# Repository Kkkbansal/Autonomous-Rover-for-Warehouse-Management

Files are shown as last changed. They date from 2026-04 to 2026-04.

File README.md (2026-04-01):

# Autonomous Rover for Warehouse Rack Inventory Management System

An intelligent autonomous rover designed for **real-time warehouse inventory auditing and management**, developed for **Inter IIT Tech Meet 14.0**.

The system performs **autonomous navigation, vertical rack scanning, QR-code detection, and real-time inventory reporting**, reducing manual audit cycles from **1–2 weeks to just 1 day** with **<1% discrepancy**.

---

## Project Overview

Warehouse inventory auditing is traditionally slow, labor-intensive, and error-prone.

This project introduces an **end-to-end autonomous scanning rover** capable of:

- Autonomous warehouse navigation
- Rack-level vertical scanning
- High-accuracy QR/barcode detection
- Real-time inventory status updates
- Low discrepancy stock verification

---

## Key Performance Targets

| Metric | Target |
|---|---|
| Horizontal Position Accuracy | ±10 cm |
| Vertical Position Accuracy | ±2 cm |
| Image Resolution | 1080p |
| QR Detection Reliability | >95% |
| Audit Cycle Time | 1 Day |
| Inventory Discrepancy | <1% |

---

## System Architecture

The rover consists of the following major subsystems:

- **Chassis System**
- **Differential Drive Mechanism**
- **Vertical Scissor Lift**
- **Power Management System**
- **Control System**
- **Path Planning Module**
- **QR Code Scanning Module**
- **Human Machine Interface (HMI)**

---

## Hardware Specifications

### Rover Specifications

- **Dimensions:** 600 × 355 mm
- **Weight:** ~20 kg
- **Rack Coverage:** 5 shelf levels
- **Vision Height Range:** 0.14 m – 1.75 m
- **Drive:** 2-wheel differential drive
- **Support:** Front and rear casters
- **Lift Mechanism:** 4-stage scissor lift
- **Battery:** 18V rechargeable battery
- **Backup Capacity:** 22000 mAh
- **Operational Time:** Up to 4 hours

---

## Sensors & Computing

- **Intel RealSense D455** for depth sensing and navigation
- **1080p Camera** for QR-code scanning
- **Jetson AGX Xavier** for high-level control and processing
- **ESP32** for real-time low-level motor control

---

## Mechanical Design

### Chassis

- Modular T-slot architecture
- High structural rigidity
- Controlled flexibility for uneven floors
- Optimized load distribution

### Drive System

- Differential drive configuration
- Zero-radius turning
- High traction wheel placement
- Robust caster-based stability

### Vertical System

A **4-stage pantograph scissor lift** is used for vertical scanning.

### Why Scissor Lift?

- Fully collapsible
- Compact design
- High vertical precision
- Safe for narrow aisle movement
- Easy field maintenance

---

## Control Architecture

The control system follows a **two-tier hierarchical structure**:

### High-Level Control
- Jetson AGX Xavier
- ROS2 (Cyclone DDS)
- Path planning
- Object detection
- QR scanning
- System supervision

### Low-Level Control
- ESP32
- PID-based motor control
- Encoder feedback processing
- Real-time closed-loop control

---

## Software Stack

- **ROS2**
- **Python**
- **C++**
- **OpenCV**
- **ESP32 Firmware**
- **MATLAB PID tuning**
- **Jetson SDK**

---

## Features

- Autonomous navigation
- Real-time mapping
- QR code scanning
- Inventory mismatch detection
- Rack height scanning
- Live bot telemetry
- Battery diagnostics
- Wi-Fi quality monitoring
- Remote start / pause / restart controls

---

## Human Machine Interface (HMI)

The HMI dashboard provides:

- Bot live status
- Battery health
- Wi-Fi status
- Live camera feed
- Sensor telemetry
- Start / stop scan controls
- Inventory alerts
- Success / caution notifications

---

## Future Improvements

### 1. Multi-Robot Swarm Coordination
Enable multiple autonomous rovers with centralized planning and distributed execution.

### 2. Enhanced Sensor Suite
Integrate:
- LiDAR
- Ultrasonic sensors
- Radar
- Thermal imaging

### 3. Robotic Arm Integration
Add manipulation capabilities for:
- pick and place
- object repositioning
- multi-angle scanning

---

## Applications

- Smart warehouses
- Inventory automation
- Industrial logistics
- E-commerce fulfillment centers
- Manufacturing storage systems

---

## Team

**Inter IIT Tech Meet 14.0**

Project: *Autonomous Rover for Warehouse Rack Inventory Management System*

---

## Acknowledgments

Special thanks to the Inter IIT Tech Meet organizers, mentors, and team members for their support in the development of this project.

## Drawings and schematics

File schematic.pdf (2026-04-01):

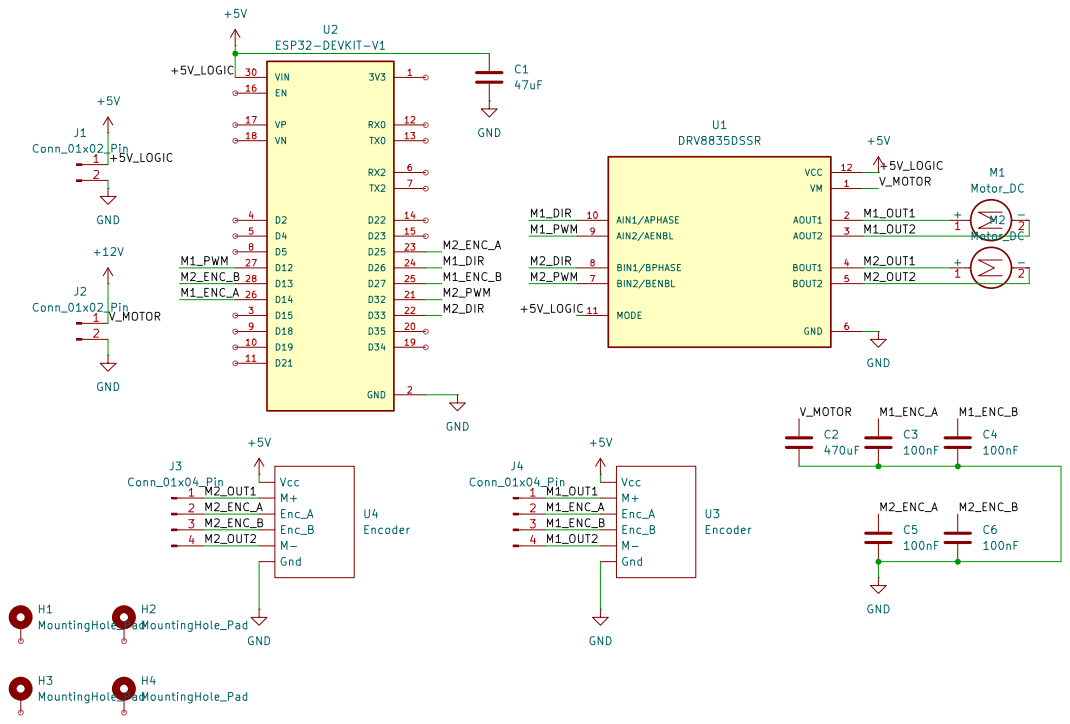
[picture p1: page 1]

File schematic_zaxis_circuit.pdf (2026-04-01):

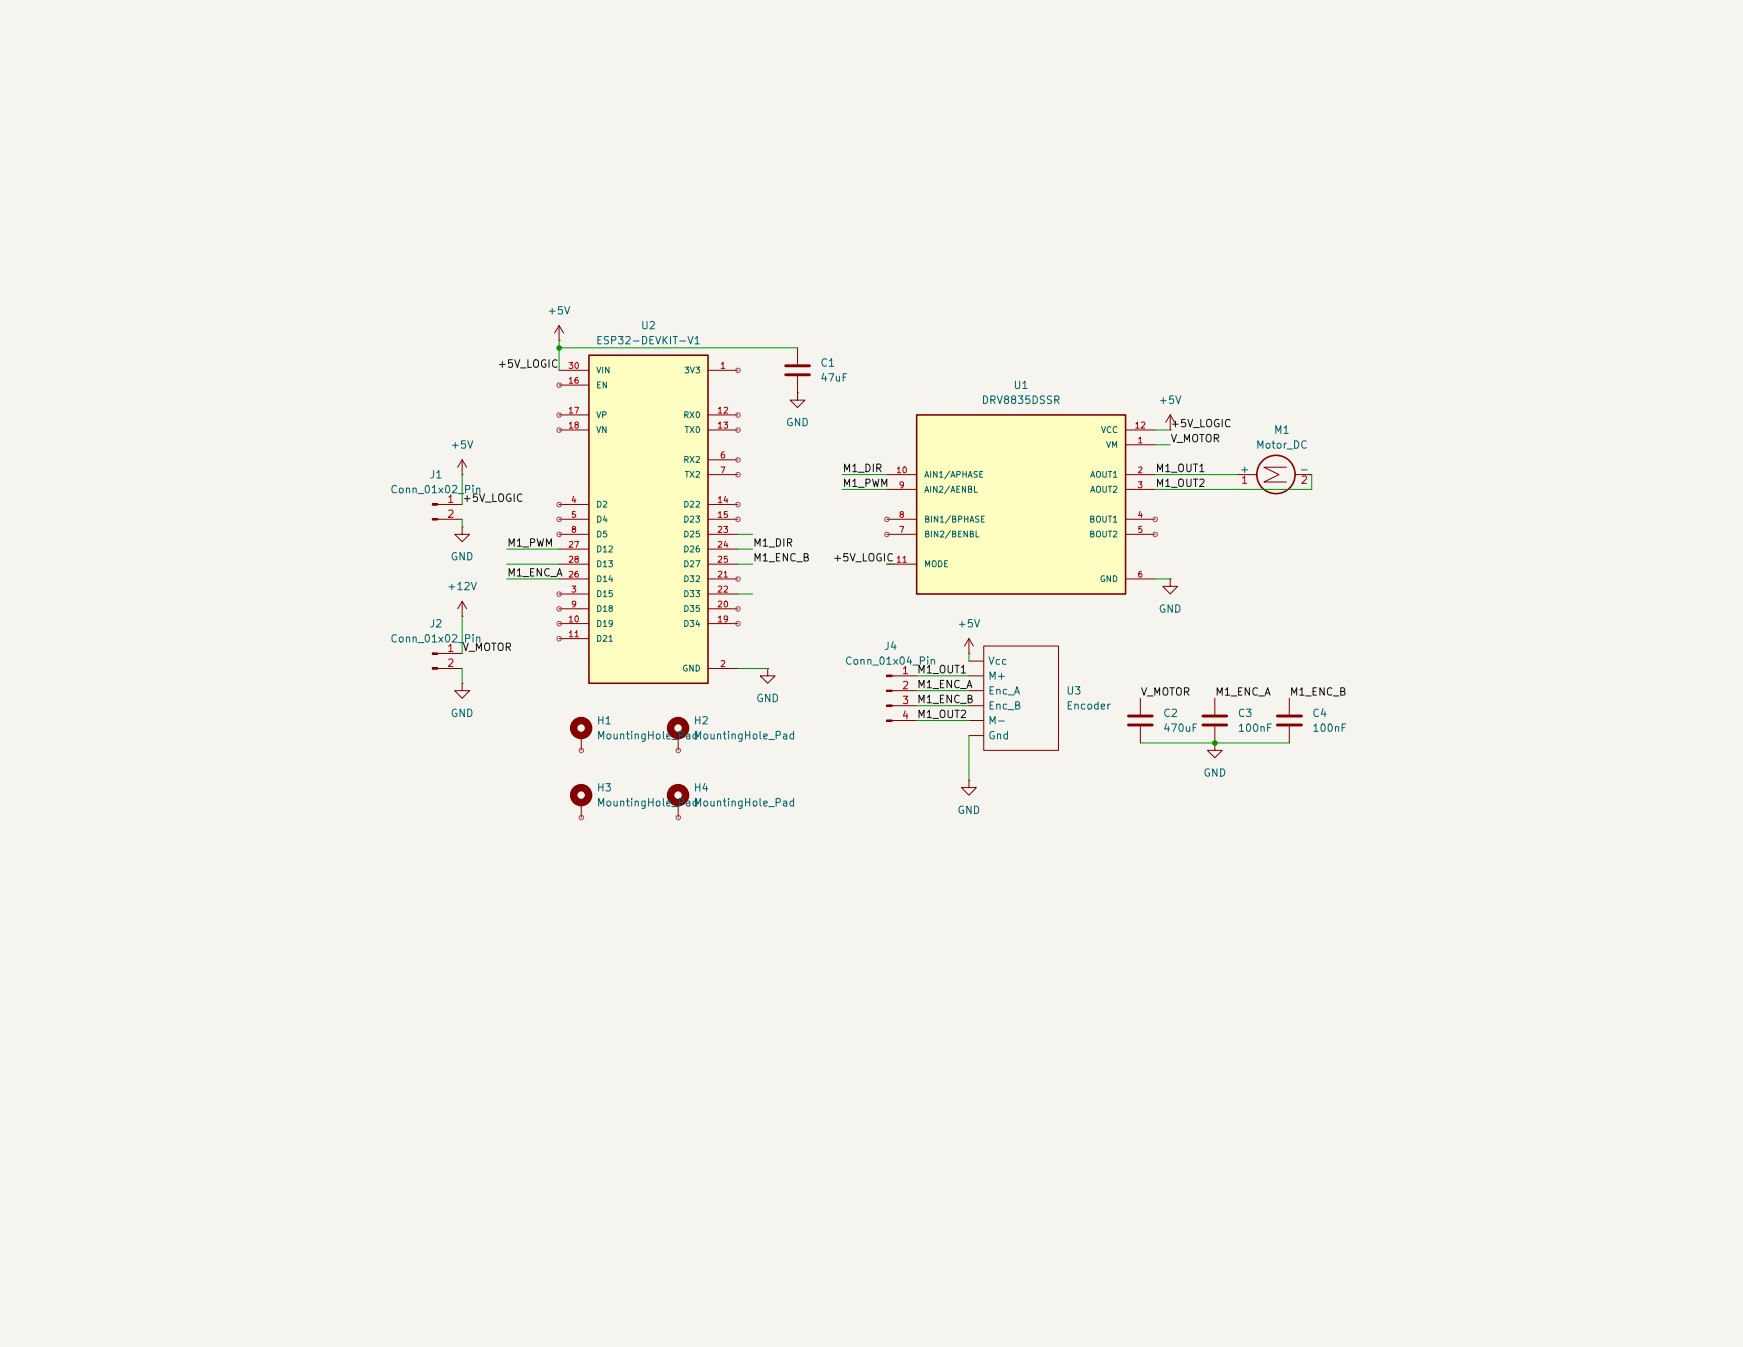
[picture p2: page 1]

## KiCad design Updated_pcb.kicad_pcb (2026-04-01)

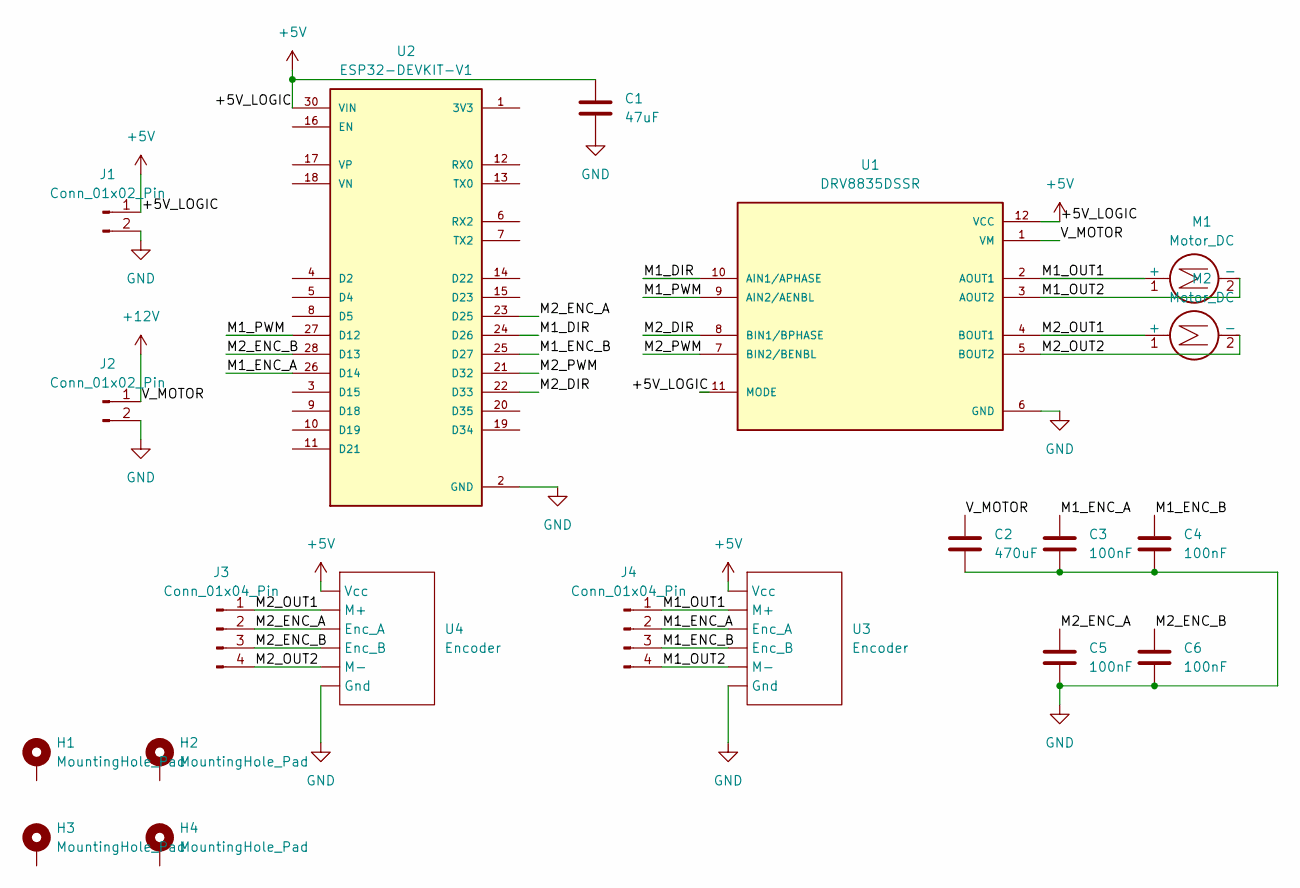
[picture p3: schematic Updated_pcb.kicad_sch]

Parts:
C1: 47uF; C_Radial_D5.0mm_H7.0mm_P2.00mm
C2: 470uF; C_Radial_D5.0mm_H7.0mm_P2.00mm
C3, C4, C5, C6: 100nF; C_Radial_D5.0mm_H7.0mm_P2.00mm
H1, H2, H3, H4: MountingHole_Pad; MountingHole_2.2mm_M2_ISO7380_Pad_TopBottom
J1, J2: Conn_01x02_Pin; PinHeader_1x02_P1.00mm_Vertical_SMD_Pin1Left
J3, J4: Conn_01x04_Pin; PinHeader_1x04_P1.00mm_Vertical_SMD_Pin1Left
M1, M2: Motor_DC; PinHeader_2x01_P2.54mm_Vertical_SMD
U1: DRV8835DSSR; SON50P300X200X80-13N; PARTREV H
U2: ESP32-DEVKIT-V1; MODULE_ESP32_DEVKIT_V1; PARTREV N/A
U3, U4: Encoder

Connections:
+5V: C1.2, J1.1, U1.11 (MODE), U1.12 (VCC), U2.30 (VIN), U3., U4.
+12V: C2.1, J2.1, U1.1 (VM)
/M1_DIR: U1.10 (AIN1/APHASE), U2.24 (D26)
/M1_ENC_A: C3.1, J4.2, U2.26 (D14), U3.
/M1_ENC_B: C4.1, J4.3, U2.25 (D27), U3.
/M1_OUT1: J4.1, M1.1 (+), U1.2 (AOUT1), U3.
/M1_OUT2: J4.4, M1.2 (-), U1.3 (AOUT2), U3.
/M1_PWM: U1.9 (AIN2/AENBL), U2.27 (D12)
/M2_DIR: U1.8 (BIN1/BPHASE), U2.22 (D33)
/M2_ENC_A: C5.1, J3.2, U2.23 (D25), U4.
/M2_ENC_B: C6.1, J3.3, U2.28 (D13), U4.
/M2_OUT1: J3.1, M2.1 (+), U1.4 (BOUT1), U4.
/M2_OUT2: J3.4, M2.2 (-), U1.5 (BOUT2), U4.
/M2_PWM: U1.7 (BIN2/BENBL), U2.21 (D32)
GND: C1.1, C2.2, C3.2, C4.2, C5.2, C6.2, J1.2, J2.2, U1.6 (GND), U1.13 (GND), U2.2 (GND), U2.29 (GND), U3., U4.

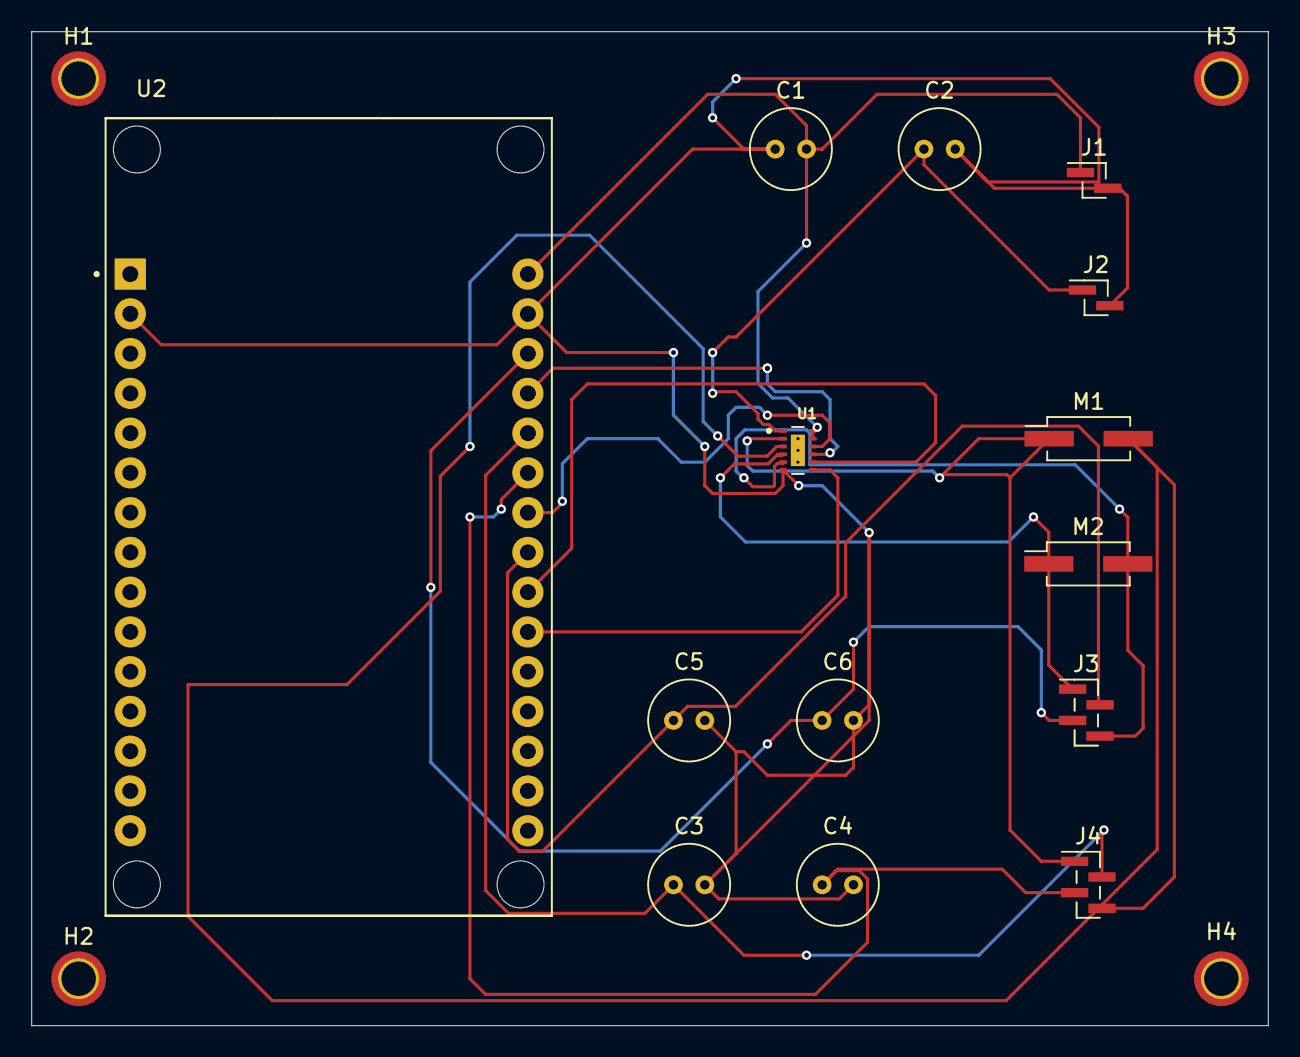
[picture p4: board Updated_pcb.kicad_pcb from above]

Board: 2 copper layers, 79.0 x 63.5 mm, 18 parts (0 on the bottom side), 15 nets.

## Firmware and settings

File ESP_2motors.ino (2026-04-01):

#include <Arduino.h>

// ===================== PIN DEFINITIONS =====================

// -------- Motor 1 pins --------
#define M1_PWM   25        // PWM pin
#define M1_DIR   26        // DIR pin
#define M1_ENC_A 35        // Encoder A
#define M1_ENC_B 13        // Encoder B

// -------- Motor 2 pins --------
#define M2_PWM   33       // PWM pin
#define M2_DIR   32        // DIR pin
#define M2_ENC_A 27        // Encoder A
#define M2_ENC_B 14        // Encoder B

// ==================== ENCODER VARIABLES ====================

volatile long enc1Count = 0;
volatile uint8_t prev1State = 0;

volatile long enc2Count = 0;
volatile uint8_t prev2State = 0;

// =================== MOTOR / PID PARAMETERS =================

const int ppr_mech = 325;
const int ppr_4x   = ppr_mech * 4;

// PID values
float Kp = 2.35f;
float Ki = 3.875f;
float Kd = 0.415f;

float integMin = -50.0f;
float integMax =  50.0f;

// PID states M1
float err1=0, prevErr1=0, integ1=0, dFiltered1=0;
float rpmFiltered1 = 0;

// PID states M2
float err2=0, prevErr2=0, integ2=0, dFiltered2=0;
float rpmFiltered2 = 0;

// Filters
const float rpmAlpha = 0.3f;
const float dAlpha   = 0.15f;

// Setpoints
float setRpm1 = 50.0f;
float setRpm2 = 50.0f;

// Timing
unsigned long lastTs = 0;
const unsigned long Ts_ms = 10;


// ====================== QUADRATURE ISR M1 =====================
void IRAM_ATTR enc1ISR() {
  uint8_t state = (digitalRead(M1_ENC_A) << 1) | digitalRead(M1_ENC_B);

  if ((prev1State == 0b00 && state == 0b01) ||
      (prev1State == 0b01 && state == 0b11) ||
      (prev1State == 0b11 && state == 0b10) ||
      (prev1State == 0b10 && state == 0b00))
    enc1Count++;
  else if ((prev1State == 0b00 && state == 0b10) ||
           (prev1State == 0b10 && state == 0b11) ||
           (prev1State == 0b11 && state == 0b01) ||
           (prev1State == 0b01 && state == 0b00))
    enc1Count--;

  prev1State = state;
}

// ====================== QUADRATURE ISR M2 =====================
void IRAM_ATTR enc2ISR() {
  uint8_t state = (digitalRead(M2_ENC_A) << 1) | digitalRead(M2_ENC_B);

  if ((prev2State == 0b00 && state == 0b01) ||
      (prev2State == 0b01 && state == 0b11) ||
      (prev2State == 0b11 && state == 0b10) ||
      (prev2State == 0b10 && state == 0b00))
    enc2Count++;
  else if ((prev2State == 0b00 && state == 0b10) ||
           (prev2State == 0b10 && state == 0b11) ||
           (prev2State == 0b11 && state == 0b01) ||
           (prev2State == 0b01 && state == 0b00))
    enc2Count--;

  prev2State = state;
}

// ====================== MOTOR HELPER =========================
void setMotor(int pwmPin, int dirPin, int val) {
  val = constrain(val, -255, 255);

  if (val >= 0) {
    digitalWrite(dirPin, LOW);
    analogWrite(pwmPin, val);
  } else {
    digitalWrite(dirPin, HIGH);
    analogWrite(pwmPin, -val);
  }
}

float pulsesToRpm(long pulses, int ppr4x, unsigned long dt_ms) {
  float dt = dt_ms / 1000.0f;
  return (pulses / (float)ppr4x) * (60.0f / dt);
}

// ============================= SETUP =========================
void setup() {
  Serial.begin(115200);

  pinMode(M1_PWM, OUTPUT);
  pinMode(M1_DIR, OUTPUT);
  pinMode(M2_PWM, OUTPUT);
  pinMode(M2_DIR, OUTPUT);

  pinMode(M1_ENC_A, INPUT);
  pinMode(M1_ENC_B, INPUT_PULLUP);

  pinMode(M2_ENC_A, INPUT);
  pinMode(M2_ENC_B, INPUT_PULLUP);

  prev1State = (digitalRead(M1_ENC_A) << 1) | digitalRead(M1_ENC_B);
  prev2State = (digitalRead(M2_ENC_A) << 1) | digitalRead(M2_ENC_B);

  attachInterrupt(M1_ENC_A, enc1ISR, CHANGE);
  attachInterrupt(M1_ENC_B, enc1ISR, CHANGE);
  attachInterrupt(M2_ENC_A, enc2ISR, CHANGE);
  attachInterrupt(M2_ENC_B, enc2ISR, CHANGE);

  lastTs = millis();
}

// ============================== LOOP ==========================
void loop() {

  unsigned long now = millis();
  if (now - lastTs >= Ts_ms) {

    unsigned long dt = now - lastTs;
    lastTs = now;

    long p1 = enc1Count; enc1Count = 0;
    long p2 = enc2Count; enc2Count = 0;

    float rpm1 = pulsesToRpm(p1, ppr_4x, dt);
    float rpm2 = pulsesToRpm(p2, ppr_4x, dt);

    rpmFiltered1 = rpmAlpha * rpm1 + (1 - rpmAlpha) * rpmFiltered1;
    rpmFiltered2 = rpmAlpha * rpm2 + (1 - rpmAlpha) * rpmFiltered2;

    float dt_s = dt / 1000.0f;

    // ===== Motor 1 PID =====
    err1 = setRpm1 - rpmFiltered1;
    integ1 += err1 * dt_s;
    integ1 = constrain(integ1, integMin, integMax);
    float dRaw1 = (err1 - prevErr1) / dt_s;
    dFiltered1 = dAlpha * dRaw1 + (1 - dAlpha) * dFiltered1;
    int out1 = (int)(Kp*err1 + Ki*integ1 + Kd*dFiltered1);
    prevErr1 = err1;

    // ===== Motor 2 PID =====
    err2 = setRpm2 - rpmFiltered2;
    integ2 += err2 * dt_s;
    integ2 = constrain(integ2, integMin, integMax);
    float dRaw2 = (err2 - prevErr2) / dt_s;
    dFiltered2 = dAlpha * dRaw2 + (1 - dAlpha) * dFiltered2;
    int out2 = (int)(Kp*err2 + Ki*integ2 + Kd*dFiltered2);
    prevErr2 = err2;

    // Apply outputs
    setMotor(M1_PWM, M1_DIR, out1);
    setMotor(M2_PWM, M2_DIR, out2);

    // Plotter-friendly output
    Serial.print("M1_set:"); Serial.print(setRpm1);
    Serial.print("\tM1_RPM:"); Serial.print(rpmFiltered1);
    Serial.print("\tM1_out:"); Serial.print(out1);

    Serial.print("\tM2_set:"); Serial.print(setRpm2);
    Serial.print("\tM2_RPM:"); Serial.print(rpmFiltered2);
    Serial.print("\tM2_out:"); Serial.println(out2);
  }
}

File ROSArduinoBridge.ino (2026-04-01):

/*********************************************************************
 * ROSArduinoBridge - DEBUG VERSION
 *********************************************************************/

#define USE_BASE      

#ifdef USE_BASE
   #define CYTRON_MOTOR_DRIVER
#endif

#undef USE_SERVOS     

#define BAUDRATE     115200
#define MAX_PWM        255

#if defined(ARDUINO) && ARDUINO >= 100
#include "Arduino.h"
#else
#include "WProgram.h"
#endif

#include "commands.h"
#include "sensors.h"

#ifdef USE_SERVOS
   #include <Servo.h>
   #include "servos.h"
#endif

#ifdef USE_BASE
  #include "motor_driver.h"
  #include "encoder_driver.h"
  #include "diff_controller.h"

  #define PID_RATE           30     
  const int PID_INTERVAL = 1000 / PID_RATE;
  unsigned long nextPID = PID_INTERVAL;
  #define AUTO_STOP_INTERVAL 2000
  long lastMotorCommand = AUTO_STOP_INTERVAL;
#endif

// Variables
int arg = 0;
int arg_index = 0;
char chr;
char cmd;
char argv1[16];
char argv2[16];
long arg1;
long arg2;

void resetCommand() {
  cmd = 0;
  memset(argv1, 0, sizeof(argv1));
  memset(argv2, 0, sizeof(argv2));
  arg1 = 0;
  arg2 = 0;
  arg = 0;
  arg_index = 0;
}

int runCommand() {
  arg1 = atoi(argv1);
  arg2 = atoi(argv2);
  
  // --- DEBUG PRINT (REMOVE LATER) ---
  // This helps us see WHY it thinks 'b' is 'a'
  Serial.print("DEBUG: Executing CMD [");
  Serial.write(cmd);
  Serial.print("] (ASCII ");
  Serial.print((int)cmd);
  Serial.print(") with Arg1: ");
  Serial.println(arg1);
  // ----------------------------------

  switch(cmd) {
  case GET_BAUDRATE:
    Serial.println(BAUDRATE);
    break;
  case ANALOG_READ:
    Serial.println(analogRead(arg1));
    break;
  case DIGITAL_READ:
    Serial.println(digitalRead(arg1));
    break;
  case ANALOG_WRITE:
    Serial.println("OK"); 
    break;
  case DIGITAL_WRITE:
    if (arg2 == 0) digitalWrite(arg1, LOW);
    else if (arg2 == 1) digitalWrite(arg1, HIGH);
    Serial.println("OK"); 
    break;
  case PIN_MODE:
    if (arg2 == 0) pinMode(arg1, INPUT);
    else if (arg2 == 1) pinMode(arg1, OUTPUT);
    Serial.println("OK");
    break;
  case PING:
    Serial.println(Ping(arg1));
    break;
#ifdef USE_SERVOS
  case SERVO_WRITE:
    servos[arg1].setTargetPosition(arg2);
    Serial.println("OK");
    break;
  case SERVO_READ:
    Serial.println(servos[arg1].getServo().read());
    break;
#endif
    
#ifdef USE_BASE
  case READ_ENCODERS:
    Serial.print(readEncoder(LEFT));
    Serial.print(" ");
    Serial.println(readEncoder(RIGHT));
    break;
   case RESET_ENCODERS:
    resetEncoders();
    resetPID();
    Serial.println("OK");
    break;
  case MOTOR_SPEEDS:
    lastMotorCommand = millis();
    if (arg1 == 0 && arg2 == 0) {
      setMotorSpeeds(0, 0);
      resetPID();
      moving = 0;
    }
    else moving = 1;
    leftPID.TargetTicksPerFrame = arg1;
    rightPID.TargetTicksPerFrame = arg2;
    Serial.println("OK"); 
    break;
  case MOTOR_RAW_PWM:
    lastMotorCommand = millis();
    resetPID();
    moving = 0; 
    setMotorSpeeds(arg1, arg2);
    Serial.println("OK"); 
    break;
  case UPDATE_PID:
    {
      char *p = argv1;
      char *str;
      int i = 0;
      int pid_args[4];
      while ((str = strtok_r(p, ":", &p)) != NULL) {
         pid_args[i] = atoi(str);
         i++;
      }
      Kp = pid_args[0];
      Kd = pid_args[1];
      Ki = pid_args[2];
      Ko = pid_args[3];
      Serial.println("OK");
    }
    break;
#endif
  default:
    Serial.println("Invalid Command");
    break;
  }
  return 0;
}

void setup() {
  Serial.begin(BAUDRATE);
  

  
  delay(1000);
  Serial.println("ESP32 Ready - Debug Mode");
  resetCommand(); // Ensure variables are clean

#ifdef USE_BASE
  initEncoders(); 
  initMotorController();
  resetPID();
#endif

#ifdef USE_SERVOS
  int i;
  for (i = 0; i < N_SERVOS; i++) {
    servos[i].initServo(
        servoPins[i],
        stepDelay[i],
        servoInitPosition[i]);
  }
#endif
}

void loop() {
  while (Serial.available() > 0) {
    chr = Serial.read();

    if (chr == 10) continue; // Ignore Newline

    if (chr == 13) { // Carriage Return
      if (arg == 1) argv1[arg_index] = 0;
      else if (arg == 2) argv2[arg_index] = 0;
      
      if (cmd > 0) {
        runCommand();
      }
      resetCommand();
    }
    else if (chr == ' ') {
      if (arg == 0) arg = 1;
      else if (arg == 1)  {
        argv1[arg_index] = 0;
        arg = 2;
        arg_index = 0;
      }
      continue;
    }
    else {
      if (arg == 0) {
        cmd = chr;
      }
      else if (arg == 1) {
        argv1[arg_index] = chr;
        arg_index++;
      }
      else if (arg == 2) {
        argv2[arg_index] = chr;
        arg_index++;
      }
    }
  }
  
#ifdef USE_BASE
  if (millis() > nextPID) {
    updatePID();
    nextPID += PID_INTERVAL;
  }
  
  if ((millis() - lastMotorCommand) > AUTO_STOP_INTERVAL) {;
    setMotorSpeeds(0, 0);
    moving = 0;
  }
#endif

#ifdef USE_SERVOS
  int i;
  for (i = 0; i < N_SERVOS; i++) {
    servos[i].doSweep();
  }
#endif
}

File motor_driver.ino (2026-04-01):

/***************************************************************
   Motor driver definitions
   
   Add a "#elif defined" block to this file to include support
   for a particular motor driver.
   Then add the appropriate
   #define near the top of the main ROSArduinoBridge.ino file.
   *************************************************************/

#ifdef USE_BASE
   
#ifdef POLOLU_VNH5019
  /* Include the Pololu library */
  #include "DualVNH5019MotorShield.h"

  /* Create the motor driver object */
  DualVNH5019MotorShield drive;
  
  /* Wrap the motor driver initialization */
  void initMotorController() {
    drive.init();
  }

  /* Wrap the drive motor set speed function */
  void setMotorSpeed(int i, int spd) {
    if (i == LEFT) drive.setM1Speed(spd);
    else drive.setM2Speed(spd);
  }

  // A convenience function for setting both motor speeds
  void setMotorSpeeds(int leftSpeed, int rightSpeed) {
    setMotorSpeed(LEFT, leftSpeed);
    setMotorSpeed(RIGHT, rightSpeed);
  }

// --- NEW SECTION FOR ESP32 + CYTRON ---
#elif defined CYTRON_MOTOR_DRIVER

  void initMotorController() {
    pinMode(LEFT_MOTOR_PWM, OUTPUT);
    pinMode(LEFT_MOTOR_DIR, OUTPUT);
    pinMode(RIGHT_MOTOR_PWM, OUTPUT);
    pinMode(RIGHT_MOTOR_DIR, OUTPUT);
  }
  
  void setMotorSpeed(int i, int spd) {
    // Cytron Driver Logic: DIR pin controls direction, PWM pin controls speed
    int dir = LOW;
    if (spd >= 0) {
      dir = HIGH;
    } else {
      dir = LOW;
      spd = -spd; // Make speed positive for PWM
    }

    // Clamp speed to 0-255
    if (spd > 255) spd = 255;

    if (i == LEFT) {
      digitalWrite(LEFT_MOTOR_DIR, dir);
      analogWrite(LEFT_MOTOR_PWM, spd);
    } else {
      digitalWrite(RIGHT_MOTOR_DIR, dir);
      analogWrite(RIGHT_MOTOR_PWM, spd);
    }
  }

  void setMotorSpeeds(int leftSpeed, int rightSpeed) {
    setMotorSpeed(LEFT, leftSpeed);
    setMotorSpeed(RIGHT, rightSpeed);
  }
// --------------------------------------

#elif defined L298_MOTOR_DRIVER
  void initMotorController() {
    digitalWrite(RIGHT_MOTOR_ENABLE, HIGH);
    digitalWrite(LEFT_MOTOR_ENABLE, HIGH);
  }
  
  void setMotorSpeed(int i, int spd) {
    unsigned char reverse = 0;
  
    if (spd < 0)
    {
      spd = -spd;
      reverse = 1;
    }
    if (spd > 255)
      spd = 255;
    
    if (i == LEFT) { 
      if      (reverse == 0) { analogWrite(LEFT_MOTOR_FORWARD, spd); analogWrite(LEFT_MOTOR_BACKWARD, 0); }
      else if (reverse == 1) { analogWrite(LEFT_MOTOR_BACKWARD, spd); analogWrite(LEFT_MOTOR_FORWARD, 0); }
    }
    else /*if (i == RIGHT) //no need for condition*/ {
      if      (reverse == 0) { analogWrite(RIGHT_MOTOR_FORWARD, spd); analogWrite(RIGHT_MOTOR_BACKWARD, 0); }
      else if (reverse == 1) { analogWrite(RIGHT_MOTOR_BACKWARD, spd); analogWrite(RIGHT_MOTOR_FORWARD, 0); }
    }
  }
  
  void setMotorSpeeds(int leftSpeed, int rightSpeed) {
    setMotorSpeed(LEFT, leftSpeed);
    setMotorSpeed(RIGHT, rightSpeed);
  }
#else
  #error A motor driver must be selected!
#endif

#endif

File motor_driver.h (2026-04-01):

/***************************************************************
   Motor driver function definitions - by James Nugen
   *************************************************************/

#ifdef L298_MOTOR_DRIVER
  #define RIGHT_MOTOR_BACKWARD 5
  #define LEFT_MOTOR_BACKWARD  6
  #define RIGHT_MOTOR_FORWARD  9
  #define LEFT_MOTOR_FORWARD   10
  #define RIGHT_MOTOR_ENABLE 12
  #define LEFT_MOTOR_ENABLE 13
#endif

// --- NEW SECTION FOR ESP32 + CYTRON ---
#ifdef CYTRON_MOTOR_DRIVER
  // Replace these numbers with your actual ESP32 GPIO pins!
  #define LEFT_MOTOR_PWM 32   // PWM Pin for Left Motor
  #define LEFT_MOTOR_DIR 33   // DIR Pin for Left Motor
  
  #define RIGHT_MOTOR_PWM 12  // PWM Pin for Right Motor
  #define RIGHT_MOTOR_DIR 26  // DIR Pin for Right Motor
#endif
// --------------------------------------

void initMotorController();
void setMotorSpeed(int i, int spd);
void setMotorSpeeds(int leftSpeed, int rightSpeed);
